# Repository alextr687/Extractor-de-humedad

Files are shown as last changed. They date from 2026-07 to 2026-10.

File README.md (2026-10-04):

# Controlador autónomo para extractor de humedad

Este proyecto nació a partir de un problema muy común en los baños domésticos. Los extractores de humedad suelen conectarse en paralelo con el alumbrado principal, de modo que se activan automáticamente cada vez que alguien enciende la luz. Aunque es una solución sencilla, tiene un inconveniente evidente: el extractor funciona siempre, independientemente de si realmente es necesario.

En mi caso decidí modificar la instalación para que el extractor pudiera accionarse manualmente mediante un interruptor independiente, sustituyendo el interruptor simple existente por uno doble.

La siguiente mejora consistió en instalar un relé temporizado a la desconexión ajustado a 30 minutos. Esto resolvía el problema de olvidarse de apagar el extractor, pero introducía otro distinto: un tiempo fijo rara vez es el adecuado. En ocasiones el baño recuperaba unas condiciones normales en pocos minutos y el extractor continuaba funcionando innecesariamente. En otras, tras una ducha prolongada, treinta minutos resultaban insuficientes para eliminar la humedad.

El objetivo pasó entonces a ser desarrollar un temporizador cuya duración dependiese del estado real del ambiente y no únicamente del tiempo transcurrido.

El proyecto consiste en el diseño de un controlador basado en Arduino capaz de gestionar automáticamente un extractor de humedad utilizando medidas de temperatura y humedad. El sistema mantiene el extractor en funcionamiento el tiempo necesario para reducir la humedad ambiental por debajo de unos umbrales configurables, evitando tanto un funcionamiento insuficiente como un consumo innecesario.

## Diseño

Desde el principio se priorizó la robustez del sistema frente a la complejidad. Los sensores de humedad de bajo coste tienden a producir lecturas erróneas, quedar bloqueados o incluso dejar de responder, especialmente en ambientes cálidos y húmedos como un cuarto de baño. Esto es especialmente relevante en condiciones en las que la humedad tiende a condensar (es decir, que el sensor se encuentre a temperatura de rocío). Por ese motivo el controlador se diseñó siguiendo un principio sencillo: ante cualquier condición anómala, el sistema debe adoptar un comportamiento predecible y seguro.

Para conseguirlo se implementaron distintos mecanismos de protección:

* filtrado de medidas mediante mediana (elimina la mayoría de outliers)
* detección de valores fuera de rango (elimina lecturas erróneas pero validadas por el sensor)
* control de tiempo de respuesta (mide el tiempo de respuesta del sensor para detectar degradación)
* detección de sensor congelado (asegura que el sensor toma medidas reales y no repetidas)
* recuperación automática mediante watchdog (incluye aviso por reinicio automático)
* modo seguro ante fallos persistentes (intento de recuperación; en caso de fallo persistente, apagado automático)
* apagado definitivo cuando no puede garantizarse un funcionamiento fiable (o cuando termina el ciclo de funcionamiento)

El esquema de la máquina de estados está disponible aquí: [Máquina de estados](docs/Programa_Arduino_(UML).pdf). 
El programa completo para Arduino IDE está en: [Programa](firmware/Programa.ino)

Además, el sistema nunca sustituye el control manual del usuario. El extractor continúa estando gobernado en última instancia por el interruptor de la instalación, de modo que siempre puede desconectarse manualmente independientemente del estado del controlador.

## Instalación

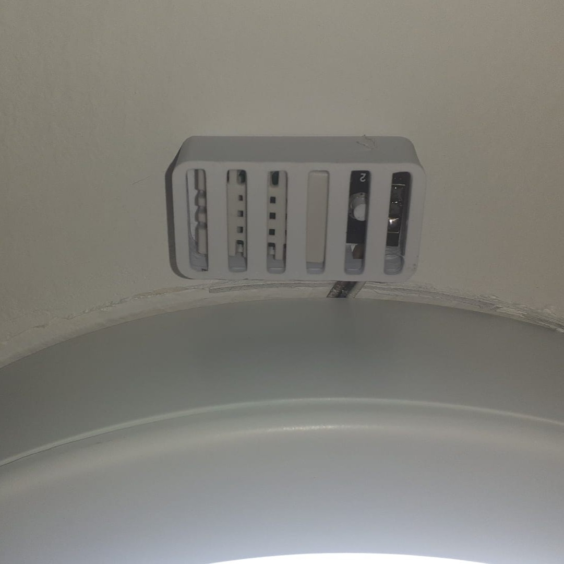
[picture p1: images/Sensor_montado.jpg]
Sensor instalado


El proyecto se integra aprovechando la instalación existente. La fuente de alimentación se encuentra en la caja de derivación del circuito de alumbrado. El controlador (Arduino y relé) está instalado sobre el falso techo, aprovechando el hueco del foco del baño. El sensor DHT22 está situado junto al punto de luz para medir la humedad ambiente. Debe colocarse lo más cerca posible del controlador para evitar ruido eléctrico (el protocolo 1-Wire[^1] es sensible a cables muy largos).  El extractor permanece conectado al interruptor manual existente, utilizándose el controlador únicamente para automatizar su desconexión. Ambos controladores (interruptor y relé) están conectados en serie, de forma que es necesario que ambos coincidan para el encendido, pero cualquiera de los dos puede apagarlo. Hay un esquema eléctrico adjunto. El objetivo fue integrar el sistema sin modificar la apariencia del baño ni añadir elementos visibles, con la única excepción del sensor de humedad relativa y temperatura, que, por su funcionamiento, debe quedar a la vista.
El esquema de la instalación eléctrica está disponible aquí: [Esquema](docs/Esquema_de_instalacion.pdf)

## Resultado

El comportamiento obtenido es considerablemente más natural que el de un temporizador convencional. El extractor permanece funcionando únicamente el tiempo necesario para reducir la humedad y se adapta automáticamente a la duración e intensidad de cada uso del baño. Aunque se trata de un proyecto doméstico, se diseñó aplicando criterios habituales en sistemas embebidos, prestando especial atención a la gestión de errores, la robustez y la seguridad de funcionamiento.

Los resultados están recogidos en la hoja de cálculo adjunta: [Hoja de resultados](tests/Data.xlsx)
En esta se muestran los siguientes datos:

* En el primer libro, dos pruebas en condiciones idénticas. Una de ellas (prueba A) muestra la evolución de la humedad con ventilación natural. La otra (prueba B) muestra la evolución en las mismas condiciones, esta vez con el extractor funcionando. Ambas pruebas terminan cuando los valores de humedad son aceptables (el mismo valor para ambas pruebas). Las condiciones iniciales de ambas pruebas están disponibles en [Condiciones iniciales](docs/Metodologia_para_la_prueba.txt)
* En el segundo libro, una ducha real en condiciones convencionales. Se muestran, además de la evolución de las humedades relativa y absoluta y la evolución de la temperatura, el estado del controlador. Esta gráfica incluye número de errores, de lecturas repetidas y estado de la máquina de estados (esperando o evaluando).
* En el tercer libro se encuentra, de nuevo, una ducha real, esta vez tras unas semanas de uso. En este caso, el controlador se vio obligado a retornar a la etapa de espera tras detectar un aumento de humedad. Se aprecian también en este ejemplo los errores del sensor. Durante esta prueba, 10 de los 130 ciclos de medición presentaron al menos una lectura no válida (7,69 % de los ciclos). Dado que cada ciclo se compone de seis lecturas de sensor independientes, la probabilidad estimada de que una lectura individual falle es de aproximadamente el 1,3 %[^2].

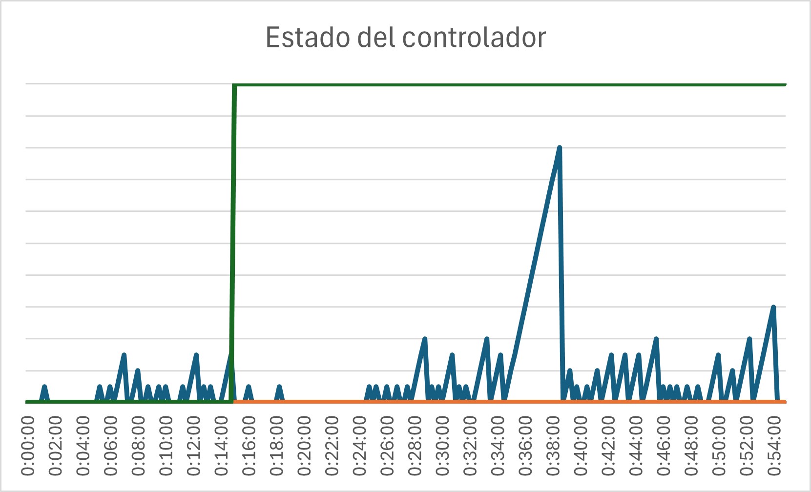
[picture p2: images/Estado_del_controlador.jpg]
Gráfica 1

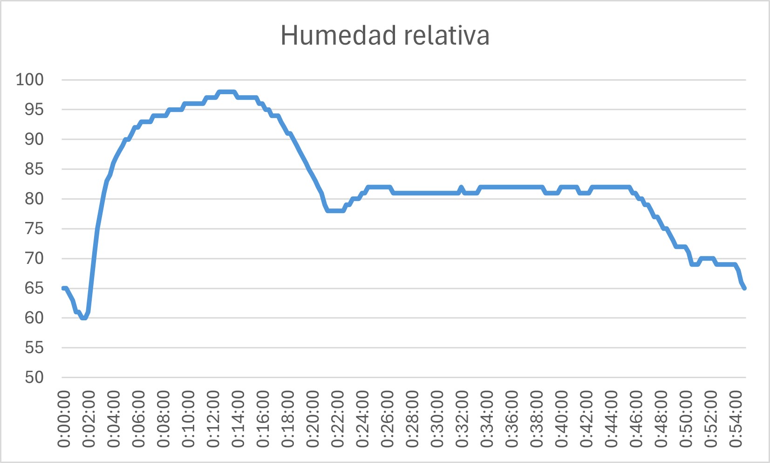
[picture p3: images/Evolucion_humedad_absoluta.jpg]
Gráfica 2

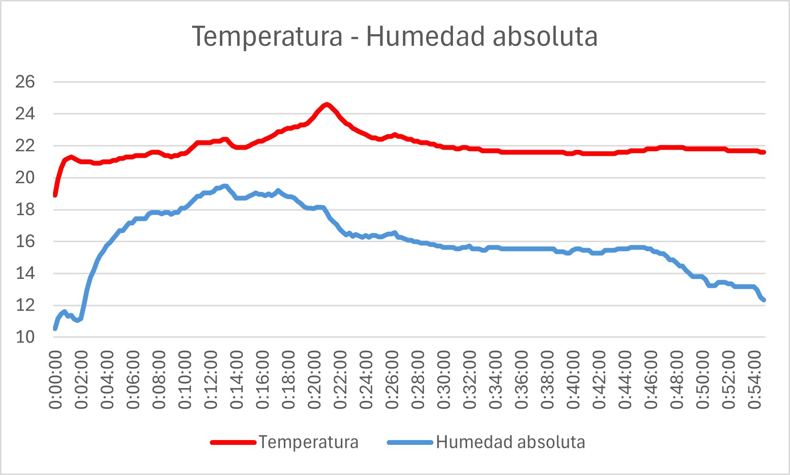
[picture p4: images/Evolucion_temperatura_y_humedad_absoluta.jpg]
Gráfica 3


Para transformar los datos del controlador en información interpretable por Excel, el siguiente parser es un script de Python que transforma documentos de texto con el formato de la salida del monitor serie en documentos tipo csv. [Script](scripts/Serial_to_csv.py)

El código [Programa_logger](firmware/Programa_logger.ino) tiene exactamente la misma función, pero añade el registro de datos en una SD. El programa registra cada 15 segundos los 9 parámetros que considera para la toma de decisiones (aproximadamente lo mismo que se imprime por monitor serie. Este registro puede ser interesante para estudios de fiabilidad a largo plazo. El resultado de la instalación del lector SD queda así:

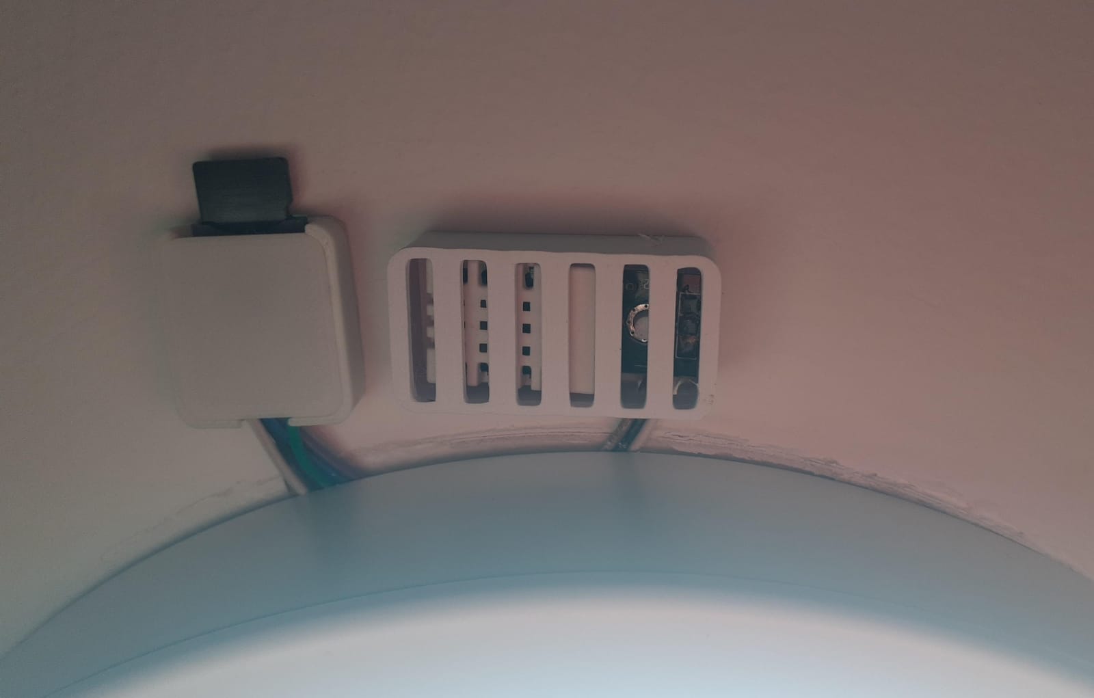
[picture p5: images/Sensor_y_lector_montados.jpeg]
Sensor y lector montados


Los archivos del registro están subidos, semana a semana, en la carpeta [long_term_data](long_term_data). Solamente identifican la semana del año, pero no el día ni la hora individualmente. 

## BOM

* Arduino Nano
* DHT22 (sustituible por DHT11 o DHT21/AM2301)
* Módulo de relé
* Zumbador pasivo
* Fuente de alimentación (5V, 5W)
* Lector de tarjetas micro-SD

## Limitaciones y posibles mejoras

* Utiliza un DHT22, que no es un sensor industrial.
* El Arduino Nano no es la plataforma definitiva para un producto comercial.
* Los umbrales son configurables únicamente modificando el firmware.

En cuanto al funcionamiento del esquema tal cual está diseñado, hay un efecto que puede resultar indeseable al usuario. La mayoría de las fuentes de alimentación tienen filtros en su salida compuestos por uno o varios condensadores, que alargan el tiempo que la fuente puede suministrar energía incluso cuando ya está desconectada. Esto se traduce en que el Nano puede seguir estando alimentado, y evitando activamente el encendido del extractor de humedad, cuando el usuario apaga y enciende el interruptor para reiniciar el sistema. Ocurrirá solamente si el usuario enciende el interruptor sin haber dejado tiempo suficiente para que se descarguen los condensadores de la fuente. Este problema puede solucionarse simplemente aumentando la carga de la fuente, con una o varias resistencias en paralelo (lo que se conoce como *bleeder resistor*), o moviendo el interruptor a la salida de la fuente, para que interrumpa solamente la alimentación del Nano (esta última solución contraviene las buenas prácticas de eficiencia energética, pero es igualmente efectiva).

## Ideas

* PCB diseñada específicamente para el proyecto.
* Sensor SHT31 o BME280.
* Configuración mediante Bluetooth o Wi-Fi.
* Actualización OTA (en caso de migrar a ESP32).
* Algoritmo adaptativo según estación del año.
* Segundo sensor fuera del baño, para comparar la humedad objetivo con la conseguida (en lugar de esperar indefinidamente hasta un umbral que puede ser inalcanzable). Mejor opción que el algoritmo adaptativo según la estación, pero más difícil de implementar.

[^1]: El DHT22 no utiliza el protocolo estándar 1-Wire® de Maxim/Dallas (que requiere direccionamiento de 64 bits y drenador abierto con resistencia pull-up), sino un protocolo propietario monobus de 40 bits impulsado por temporización de pulsos.

[^2]: Matemáticamente 1-(1-p)^6 = 0,0769 → p ≈ 1,33%. Sin embargo, el análisis omite que en sensores DHT22 en ambientes saturados (100% HR / temperatura de rocío) los fallos de lectura presentan dependencia temporal/correlación por saturación de la membrana, por lo que la asunción de independencia estocástica estricta no es válida sin un filtrado previo. En cualquier caso, sirve como aproximación «a ojo de buen cubero».

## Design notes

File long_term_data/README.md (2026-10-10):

En esta carpeta se almacenan los datos recogidos por el controlador de forma autónoma. 

Cambios en el programa por orden cronológico de implementación:

* 11/10/2026: commit *Fe de errores. Corrección de la llamada a registrar_datos* (55f73cce03b235f29c37be379a4c0f51117d4510)

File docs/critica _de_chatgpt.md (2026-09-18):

Alejandro: 

Quiero que realices una **evaluación técnica completa, crítica y objetiva de este proyecto**. No quiero una valoración superficial ni que simplemente destaques lo positivo. Quiero que intentes detectar problemas, puntos débiles, errores de diseño, decisiones mejorables y oportunidades de mejora, pero sin proponer cambios por el mero hecho de cambiar algo.

### 1\. Comprensión del proyecto

Antes de evaluarlo, reconstruye mentalmente el proyecto a partir de toda la información que te proporcione.

Identifica:

-   Objetivo principal.
-   Objetivos secundarios.
-   Requisitos y restricciones.
-   Arquitectura general.
-   Principio de funcionamiento.
-   Componentes y materiales.
-   Diseño mecánico.
-   Diseño eléctrico/electrónico.
-   Software, si lo hay.
-   Proceso de fabricación y montaje.
-   Uso previsto y condiciones de funcionamiento.

Si existe información insuficiente para entender correctamente alguna parte importante, indícalo explícitamente en lugar de asumirla.

### 2\. Evaluación técnica

Analiza por separado:

**Diseño funcional**

-   Si cumple realmente el objetivo planteado.
-   Robustez del funcionamiento.
-   Posibles modos de fallo.
-   Comportamiento en condiciones normales y anómalas.
-   Dependencias o puntos únicos de fallo.

**Diseño eléctrico/electrónico**

-   Dimensionamiento.
-   Tensiones, corrientes y potencias.
-   Protecciones.
-   Calentamiento y disipación.
-   Caídas de tensión.
-   Compatibilidad entre componentes.
-   Seguridad eléctrica.
-   Fiabilidad de conexiones y cableado.

**Diseño mecánico**

-   Resistencia.
-   Rigidez.
-   Uniones.
-   Tolerancias.
-   Concentraciones de tensión.
-   Vibraciones, golpes o cargas relevantes.
-   Protección frente al entorno.
-   Facilidad de montaje y desmontaje.

**Materiales y fabricación**

-   Adecuación de los materiales.
-   Proceso de fabricación.
-   Tolerancias razonables.
-   Limitaciones del proceso utilizado.
-   Repetibilidad.
-   Facilidad de fabricación.
-   Posibles problemas de envejecimiento o degradación.

**Software**, si procede:

-   Arquitectura.
-   Lógica de funcionamiento.
-   Estados y transiciones.
-   Gestión de errores.
-   Temporización.
-   Uso de memoria y recursos.
-   Bloqueos o comportamientos inesperados.
-   Mantenibilidad.

### 3\. Seguridad y fiabilidad

Busca específicamente situaciones en las que el proyecto pueda:

-   Fallar.
-   Dañarse.
-   Provocar daños a otros elementos.
-   Crear un riesgo para las personas.
-   Degradarse con el tiempo.
-   Comportarse de forma distinta a la esperada.

Distingue entre:

-   Problemas demostrados.
-   Riesgos técnicamente plausibles.
-   Posibilidades meramente especulativas.

No presentes una posibilidad hipotética como si fuera un problema real.

### 4\. Cumplimiento técnico y normativo

Cuando sea relevante, analiza las normas, reglamentos o buenas prácticas aplicables.

Si haces referencia a una norma, reglamento o requisito legal:

-   Indica cuál es.
-   Explica qué parte es relevante.
-   No inventes requisitos.
-   Distingue entre obligación normativa y recomendación de diseño.

Si no puedes verificar una cuestión normativa, dilo explícitamente.

### 5\. Análisis de las decisiones de diseño

Para cada decisión importante, intenta determinar:

1.  Qué problema resuelve.
2.  Qué ventajas proporciona.
3.  Qué inconvenientes introduce.
4.  Qué alternativas razonables existen.
5.  En qué condiciones sería preferible cada alternativa.

No presupongas que una alternativa es mejor simplemente porque sea más sofisticada, cara, moderna o técnicamente compleja.

### 6\. Mejoras

Propón mejoras únicamente cuando exista una razón técnica concreta.

Para cada mejora indica:

-   Problema que resuelve.
-   Cambio propuesto.
-   Beneficio esperado.
-   Coste o complejidad adicional.
-   Posibles inconvenientes.
-   Prioridad.

Clasifica las mejoras como:

-   **Crítica:** debería corregirse antes de utilizar el proyecto.
-   **Importante:** mejora significativamente la seguridad, fiabilidad o funcionamiento.
-   **Conveniente:** aporta una mejora razonable, pero no es necesaria.
-   **Opcional:** mejora principalmente aspectos secundarios, estética, comodidad o experimentación.

No propongas cambios si el diseño actual ya es adecuado para su objetivo.

### 7\. Evaluación experimental

Si proporciono mediciones, pruebas o resultados experimentales:

-   Comprueba si las conclusiones están justificadas por los datos.
-   Busca variables no controladas.
-   Analiza errores de medida.
-   Diferencia correlación de causalidad.
-   Comprueba si el número de pruebas es suficiente para la conclusión que se pretende obtener.
-   Propón experimentos adicionales solamente cuando puedan aportar información relevante.

Si hay cálculos, compruébalos.

Si hay datos suficientes, realiza tú mismo los cálculos necesarios para comprobarlos.

### 8\. Iteraciones del diseño

Si proporciono versiones anteriores del proyecto, compara las iteraciones.

Determina:

-   Qué problemas solucionó cada versión.
-   Qué características se conservaron correctamente.
-   Qué compromisos aparecieron.
-   Si alguna modificación empeoró otro aspecto.
-   Si existe alguna mejora que todavía tenga una justificación técnica clara.

No supongas que una versión posterior es necesariamente mejor.

### 9\. Calidad de ingeniería

Evalúa también el proyecto como trabajo de ingeniería:

-   Claridad de requisitos.
-   Trazabilidad entre requisitos y soluciones.
-   Justificación de decisiones.
-   Coherencia entre diseño teórico y construcción real.
-   Documentación.
-   Reproducibilidad.
-   Mantenibilidad.
-   Facilidad de reparación.
-   Escalabilidad o reutilización, cuando sea relevante.
-   Relación entre complejidad y beneficio.

### 10\. Valoración final

Termina con una síntesis estructurada que incluya:

**Fortalezas principales**  
Qué está particularmente bien resuelto y por qué.

**Debilidades principales**  
Qué aspectos presentan problemas o riesgos y por qué.

**Errores o decisiones cuestionables**  
Solo cuando exista una justificación técnica clara.

**Mejoras recomendadas**  
Ordenadas por prioridad, sin convertir la lista en una colección de cambios cosméticos.

**Aspectos que NO modificarías**  
Indica qué decisiones consideras adecuadas y explica por qué. No busques mejoras artificiales.

**Preguntas pendientes**  
Solo las preguntas cuya respuesta pueda cambiar significativamente la evaluación.

### Criterios importantes

Quiero una evaluación **crítica, no complaciente**, pero también **proporcional al objetivo real del proyecto**.

No evalúes un proyecto doméstico como si fuera un producto industrial certificado si ese no es su propósito. Evalúa cada decisión en función de sus requisitos, entorno de uso, coste, complejidad y nivel de exigencia.

No confundas:

-   «Podría hacerse de otra manera» con «está mal diseñado».
-   «Existe una solución más sofisticada» con «la solución actual es inadecuada».
-   «No está certificado» con «es técnicamente inseguro».
-   Preferencias personales con requisitos técnicos.

Cuando critiques una decisión, explica **el mecanismo físico, matemático, eléctrico, mecánico o lógico que justifica la crítica**.

Cuando una conclusión dependa de una suposición, comienza esa línea con **\[Inferencia\]** o **\[No verificado\]**.

Si existen varias soluciones técnicamente válidas, no elijas arbitrariamente una: explica el compromiso entre ellas.

No intentes agradarme ni defender mis decisiones. Tampoco las critiques por defecto. Tu objetivo es determinar, con la información disponible, **qué está bien, qué está mal, qué es mejorable y qué no merece la pena tocar**.

Quiero que señales tanto los problemas que yo pueda no haber detectado como las decisiones que están bien justificadas aunque inicialmente puedan parecer poco convencionales.

Finalmente, si detectas que falta información importante, **pregúntamela antes de emitir una conclusión definitiva sobre ese aspecto**.

A continuación te adjunto toda la documentación del proyecto. Todo el contexto necesario está en el documento llamado README  
Extractor-de-humedad-(GitHub).zip

ChatGPT: 

Ha pensado durante 3m 28s

He revisado el contenido del ZIP completo: README, firmware, máquina de estados, esquema eléctrico, metodología de ensayo, datos brutos, Excel, script de conversión, imágenes y modelo STL. La evaluación siguiente se basa en esa documentación y, donde corresponde, en documentación técnica y normativa externa actualizada.

## 1\. Reconstrucción del proyecto

### Objetivo principal

El proyecto no es realmente un "extractor automático" completo en el sentido de detectar una ducha y arrancar el ventilador por sí mismo.

Es más preciso describirlo como:

> **Controlador automático de desconexión de un extractor previamente activado manualmente, cuya duración se adapta a la evolución de temperatura y humedad.**

El interruptor del baño sigue siendo el mando primario. Al activar el sistema:

1.  Arduino arranca.
    
2.  El relé se pone en ON.
    
3.  El extractor queda habilitado, siempre que el interruptor manual también esté cerrado.
    
4.  Durante 15 minutos no se permite terminar el ciclo por humedad.
    
5.  Después se evalúa periódicamente la humedad.
    
6.  El extractor se desconecta cuando:
    
    -   humedad absoluta ≤ 13 g/m³ **y**
        
    -   humedad relativa ≤ 65 %,
        
    -   o se alcanza el tiempo máximo de 60 min,
        
    -   o se detectan determinados fallos persistentes del sensor.
        
7.  Arduino apaga el relé y entra en `SLEEP_MODE_PWR_DOWN` indefinidamente.

Esta arquitectura es coherente con el problema que planteas: **automatizar el apagado sin perder el control manual**.

---

# 2\. Arquitectura y funcionamiento

La arquitectura general es sencilla:

**Red 230 V → interruptor manual → contacto del relé → extractor**

y, en paralelo desde la alimentación:

**Red → fuente 5 V → Arduino → relé + DHT22 + zumbador**

El DHT22 proporciona temperatura y humedad. El software calcula además humedad absoluta mediante:

AH\=273.15+T2.1674RHPv(T)

con una aproximación de Magnus-Tetens para la presión de vapor.

La máquina de estados es:

-   `etapaEspera`
    
-   `etapaTest`
    
-   `etapaError`
    
-   `etapaHumedad`
    
-   `etapaTiempo`
    
-   `etapaApagado`

La idea general está bien estructurada para un proyecto embebido pequeño. No hay una arquitectura innecesariamente compleja.

---

# 3\. Lo que está particularmente bien resuelto

## 3.1. La decisión de utilizar humedad absoluta además de relativa

Esta es, en mi opinión, una de las decisiones técnicamente más justificadas del proyecto.

La humedad relativa depende mucho de la temperatura. Por ejemplo, la misma cantidad de vapor puede representar porcentajes de HR muy distintos a diferentes temperaturas.

Usar simultáneamente:

-   HR ≤ 65 %
    
-   AH ≤ 13 g/m³

evita depender exclusivamente de una variable que cambia con la temperatura.

El cálculo implementado es matemáticamente coherente para las unidades utilizadas.

**No modificaría esto simplemente por utilizar otro algoritmo más sofisticado.**

---

## 3.2. El límite de tiempo máximo

El hecho de disponer de un límite duro de funcionamiento es bueno.

Un controlador basado exclusivamente en:

> "seguir ventilando hasta que el sensor diga que todo está bien"

tiene un problema evidente si el sensor o el modelo ambiental fallan.

El límite de 60 minutos introduce una barrera independiente.

El problema está en cómo se implementa ese límite, que veremos más adelante.

---

## 3.3. La mediana de tres medidas

La función:

```
C++

```
floatmediana(floata, floatb, floatc)
```
```

está correctamente implementada.

Además, utilizar una mediana es razonable para un sensor barato en un entorno donde pueden aparecer lecturas puntuales incorrectas.

No veo justificación para sustituirla por un filtro mucho más complejo.

---

## 3.4. El sistema no confía ciegamente en `NaN`

El software contempla:

-   `NaN`
    
-   valores fuera de rango
    
-   lecturas excesivamente lentas
    
-   valores repetidos
    
-   watchdog
    
-   recuperación
    
-   segundo fallo

Eso demuestra una preocupación real por la degradación del sensor, y no solamente por el funcionamiento nominal.

La separación entre:

> "el sensor ha fallado una vez"

y

> "el sistema ya no confía en él"

es conceptualmente buena.

---

## 3.5. El watchdog

Utilizar watchdog es apropiado.

Especialmente porque el propio código reconoce que el timeout software:

```
C++

```
if (millis() -tiempoLectura>TIMEOUT_SENSOR)
```
```

**no puede detectar un bloqueo dentro de `dht.readHumidity()`** si esa función no retorna.

El watchdog cubre precisamente esa clase de problema.

La filosofía es correcta aunque la estrategia completa tiene una deficiencia importante que veremos después.

---

## 3.6. El apagado final es deliberadamente definitivo

Esta parte:

```
C++

```
digitalWrite(RELAY, LOW);
...
wdt_disable();
...
set_sleep_mode(SLEEP_MODE_PWR_DOWN);
...
while (true) sleep_cpu();
```
```

hace que el sistema no intente reiniciar continuamente el ciclo.

Para este proyecto es una decisión razonable.

La siguiente activación del interruptor vuelve a alimentar el sistema y comienza un nuevo ciclo.

No intentaría convertir esto en un sistema "siempre encendido" simplemente porque técnicamente sea posible.

---

# 4\. Problemas y puntos débiles importantes

Aquí empieza la parte crítica.

Hay varios problemas que considero reales, no simplemente preferencias.

---

# 4.1. \[Crítico\] El watchdog puede provocar reinicios indefinidos sin llegar al apagado seguro

Este es probablemente el problema de software más importante.

El flujo es:

```
C++

```
wdt_enable(WDTO_8S);
```
```

Si el programa se bloquea, el watchdog reinicia el microcontrolador.

Pero después del reinicio:

```
C++

```
digitalWrite(RELAY, HIGH);
```
```

vuelve a activar el extractor.

Y el programa continúa funcionando.

Si el sensor o alguna condición externa provoca sistemáticamente:

> arranque → bloqueo → watchdog → reinicio → arranque → bloqueo...

el sistema puede permanecer indefinidamente en ese ciclo.

No existe un contador persistente del tipo:

> "tres watchdog resets consecutivos → fallo permanente → relé OFF".

El propio README presenta el watchdog como mecanismo de recuperación y el fallo persistente como condición de apagado, pero **un reinicio por watchdog no incrementa `contadorFallos`**.

### Consecuencia

\[Inferencia\] Un fallo que produzca un bloqueo repetitivo del firmware puede mantener el extractor funcionando indefinidamente.

No significa que vaya a ocurrir en condiciones normales, pero el mecanismo de protección no cubre realmente ese caso.

### Mejora

**Importante**

Registrar resets por watchdog en una variable persistente durante el ciclo de alimentación y establecer, por ejemplo:

> primer watchdog → recuperación  
> segundo watchdog → recuperación controlada  
> watchdog repetido → relé OFF

La implementación exacta dependería de cómo quieras tratar la pérdida de sensor.

---

# 4.2. \[Crítico\] El "tiempo máximo de 60 minutos" no es realmente un máximo global

Esta línea es especialmente importante:

```
C++

```
tiempoInicio = millis();
```
```

se ejecuta al principio.

Pero también se ejecuta cuando se detecta:

```
C++

```
Nuevoaumento dehumedad detectado. Reiniciando temporizador...
```
```

Por tanto, el límite:

```
C++

```
TIEMPO_MAX = 3600000
```
```

es realmente:

> **60 minutos desde el último reinicio del temporizador**

y no:

> **60 minutos desde el comienzo del ciclo completo.**

Por ejemplo, conceptualmente podría suceder:

-   minuto 0 → comienza ciclo
    
-   minuto 50 → humedad vuelve a aumentar
    
-   se reinicia `tiempoInicio`
    
-   minuto 65 → todavía pueden quedar 45 minutos
    
-   minuto 110 → vuelve a aumentar
    
-   se reinicia otra vez

\[Inferencia\] Bajo una secuencia suficientemente persistente de aumentos de humedad, el extractor podría funcionar durante un tiempo arbitrariamente superior a 60 minutos.

Eso contradice parcialmente la descripción de "tiempo máximo de funcionamiento".

### Mejora

**Importante**

Separar:

```
```
tiempoInicioCiclo
tiempoInicioEvaluacion
```
```

y decidir explícitamente cuál de ellos limita el tiempo absoluto.

Yo conservaría el mecanismo de reinicio del temporizador si tiene una justificación experimental, pero **mantendría además un timeout absoluto independiente**.

---

# 4.3. La afirmación de "seis lecturas independientes" no es correcta

El README afirma:

> cada ciclo se compone de seis lecturas de sensor independientes.

El código hace:

```
C++

```
h[0] = dht.readHumidity();
t[0] = dht.readTemperature();

h[1] = dht.readHumidity();
t[1] = dht.readTemperature();

h[2] = dht.readHumidity();
t[2] = dht.readTemperature();
```
```

Pero la librería Adafruit DHT utiliza un intervalo mínimo de 2 s y, si no ha pasado ese tiempo, devuelve la medición anterior en vez de iniciar una nueva adquisición. La implementación actual de la librería muestra explícitamente `MIN_INTERVAL 2000` y ese comportamiento. [GitHub+1](https://github.com/adafruit/DHT-sensor-library/blob/master/DHT.cpp?utm_source=chatgpt.com)

En este proyecto hay 5 s entre ciclos, por lo que las tres adquisiciones separadas por 5 s sí son adquisiciones nuevas.

Pero dentro de cada adquisición:

```
```
readHumidity()
readTemperature()
```
```

ambas proceden de **la misma trama de 40 bits del DHT22**.

Por tanto:

-   3 adquisiciones físicas del DHT22
    
-   cada adquisición proporciona HR + T

No son seis mediciones independientes.

Además, el DHT22 tiene una frecuencia máxima de aproximadamente 0,5 Hz, es decir, una medición cada 2 s. [Adafruit+1](https://www.adafruit.com/product/385?utm_source=chatgpt.com)

---

## 4.4. La estimación estadística de la tasa de error está mal planteada

El README calcula:

1−(1−p)6\=0.0769

y obtiene:

p≈1.33%

Pero, por lo anterior, el supuesto de seis lecturas independientes no corresponde al código.

Si se consideran **tres adquisiciones independientes** por ciclo:

1−(1−p)3\=0.0769

se obtiene aproximadamente:

p≈2.63%

Y utilizando los datos brutos disponibles, hay además una discrepancia en el número de ciclos.

El fichero `Ducha_real_II.txt` contiene:

-   129 líneas de medición, contando errores como ciclos de medición.
    
-   10 de ellas son errores.
    
-   1 evento explícito de reinicio del temporizador.

Eso da:

12910\=7.75%

no 7,69 %.

La diferencia porcentual es pequeña, pero para un proyecto que intenta caracterizar estadísticamente la fiabilidad del sensor, **la metodología debería ser más rigurosa**.

---

# 4.5. El contador de "sensor congelado" puede confundir estabilidad real con fallo

El criterio es:

```
C++

```
if (
  fabs(humedad-prev_humedad) <RESOLUCION_SENSOR&&fabs(temperatura-prev_temperatura) <RESOLUCION_SENSOR
)
    contadorIguales++;
```
```

y:

```
C++

```
MAX_LECTURAS_IGUALES = 20;
```
```

es decir, unos 5 minutos.

El problema es que:

> "el sensor lleva cinco minutos dando exactamente lo mismo"

no implica necesariamente:

> "el sensor está congelado".

El propio DHT22 tiene resolución de 0,1 %HR y 0,1 °C, y es un sensor relativamente lento. [GitHub+1](https://github.com/adafruit/DHT-sensor-library/blob/master/DHT.cpp?utm_source=chatgpt.com)

Además, en los datos reales aparece un ejemplo muy interesante:

```
```
21.6 °C
82.0 %
15.55 g/m³
```
```

mantenido durante aproximadamente cuatro minutos.

El contador llegó a:

```
```
16
```
```

sin que existiese evidencia de fallo.

Por tanto, el sistema estuvo bastante cerca del umbral de "sensor congelado" en una situación que parece perfectamente plausible.

### Evaluación

**Riesgo técnicamente plausible, no fallo demostrado.**

El criterio debería considerar algo más que igualdad exacta, por ejemplo:

-   tiempo sin variación;
    
-   coherencia entre temperatura y humedad;
    
-   respuesta ante una pequeña perturbación;
    
-   quizá evolución de la señal en ventanas más largas.

Pero no sustituiría automáticamente el método por otro más complejo.

---

# 4.6. `contadorHumedadAlta` tampoco cuenta realmente "2 minutos consecutivos"

El comentario dice:

```
C++

```
CICLOS_HUMEDAD_ALTA = 8//2 minuto con humedad relativa aumentando
```
```

pero el código:

```
C++

```
if ((humedad-prev_humedad) >=UMBRAL_AUMENTO)
    contadorHumedadAlta++;
```
```

**no reinicia el contador cuando la humedad deja de aumentar**.

Solamente lo reduce ante un error:

```
C++

```
if (variableError<0)
    contadorHumedadAlta--;
```
```

Por tanto, el contador representa:

> número acumulado de incrementos suficientemente grandes

y no:

> ocho incrementos consecutivos durante dos minutos.

Eso es una discrepancia entre especificación y código.

\[Inferencia\] Una humedad que oscile alrededor de un nivel alto podría acumular suficientes incrementos separados para reiniciar el temporizador aunque no exista una tendencia ascendente continua.

Esto sí merece corrección porque afecta directamente a la lógica funcional.

---

# 4.7. El watchdog está bien planteado, pero el relé tiene una filosofía "fail ON"

En `setup()`:

```
C++

```
digitalWrite(RELAY, HIGH);
```
```

y el relé permanece activado durante todo el funcionamiento normal.

Eso significa que ante determinados fallos:

-   bloqueo de software;
    
-   reinicio;
    
-   comportamiento inesperado del programa;

el estado deseado del sistema es **extractor encendido**.

Esto tiene una justificación razonable:

> ante incertidumbre sobre la humedad, es preferible ventilar.

Pero no debe confundirse con un estado "seguro" en todos los sentidos.

Para este proyecto:

-   fallo ON → más consumo / más funcionamiento;
    
-   fallo OFF → humedad potencialmente no evacuada.

El primero parece razonable para un extractor doméstico.

Además, el interruptor manual proporciona una segunda vía de desconexión, lo cual es una buena decisión arquitectónica.

---

# 5\. DHT22: elección y tratamiento

El DHT22 es suficiente para un proyecto doméstico de estas características.

El fabricante/distribuidor documenta aproximadamente:

-   0–100 % HR;
    
-   ±2–5 % HR;
    
-   −40 a 80 °C;
    
-   ±0,5 °C;
    
-   máximo 0,5 Hz. [Adafruit](https://www.adafruit.com/product/385?utm_source=chatgpt.com)

Por tanto, **no considero que utilizar DHT22 sea un error de diseño**.

El hecho de que no sea industrial tampoco es, por sí mismo, una deficiencia.

### Donde sí veo limitación

El proyecto intenta hacer decisiones relativamente importantes a partir de diferencias pequeñas:

```
C++

```
AH_LIMITE = 13.0
H_LIMITE = 65.0
```
```

y el propio sensor tiene una precisión de humedad bastante peor que 1 % en términos absolutos. [Adafruit](https://www.adafruit.com/product/385?utm_source=chatgpt.com)

Esto no significa que el sistema no funcione. Significa que:

> 65 % no debe interpretarse como una frontera físicamente exacta.

En realidad el controlador utiliza los umbrales como **criterios de decisión**, no como medición metrológica.

Eso está bien si se entiende así.

---

# 6\. Diseño eléctrico

Aquí la documentación es mucho más débil que el software.

## 6.1. Potencia de 5 V

Una fuente de:

**5 V × 5 W = 1 A**

tiene, en principio, margen enorme para:

-   Nano;
    
-   DHT22;
    
-   relé;
    
-   zumbador.

El DHT22 consume del orden de 2,5 mA durante conversión. [Adafruit](https://www.adafruit.com/product/385?utm_source=chatgpt.com)

Por tanto, **5 W no parece una elección problemática por falta de potencia**.

Pero falta el dato realmente importante:

> modelo exacto de la fuente.

No sabemos:

-   aislamiento;
    
-   certificaciones;
    
-   protección contra cortocircuito;
    
-   temperatura máxima;
    
-   comportamiento térmico;
    
-   grado IP;
    
-   corriente real disponible;
    
-   tipo de montaje;
    
-   si es una fuente apropiada para instalación permanente.

---

## 6.2. Atención al punto de alimentación del Nano

El esquema parece alimentar el Nano directamente con 5 V regulados.

Eso es correcto para el pin de 5 V.

No sería equivalente introducir 5 V por VIN.

La documentación actual de Arduino especifica para el Nano clásico alimentación mediante USB o VIN, siendo VIN una entrada que pasa por el regulador; la documentación del modelo muestra 7–12 V como rango de VIN. [Documentación de Arduino+1](https://docs.arduino.cc/resources/datasheets/A000005-datasheet.pdf?utm_source=chatgpt.com)

Por tanto:

**5 V regulados → pin 5V**

es la arquitectura que corresponde al esquema.

Esto debería quedar escrito explícitamente en la documentación.

---

# 7\. Inconsistencia importante: Nano frente a UNO

El BOM dice:

> Arduino Nano

pero el esquema eléctrico contiene gráficamente un:

> **Arduino UNO**

No es simplemente estética.

Los pines utilizados son compatibles conceptualmente porque ambos emplean ATmega328P en las versiones clásicas, pero:

-   dimensiones;
    
-   conectores;
    
-   montaje;
    
-   alimentación;
    
-   ubicación física de pines;

son diferentes.

Por tanto, para reproducibilidad esto es un error documental claro.

### Prioridad

**Conveniente / Importante para documentación**, pero no necesariamente un problema funcional.

Yo corregiría el esquema para representar exactamente el hardware instalado.

---

# 8\. Relé y extractor

Aquí falta información para cerrar la evaluación.

No aparece:

-   fabricante/modelo del módulo de relé;
    
-   tensión de bobina;
    
-   corriente de bobina;
    
-   especificación del contacto;
    
-   categoría de utilización;
    
-   carga inductiva admisible;
    
-   tensión nominal exacta del extractor;
    
-   potencia del extractor;
    
-   corriente de arranque.

Esto es importante.

Un extractor es un motor, por lo que la carga no debe tratarse simplemente como:

> "por ejemplo 30 W → 0,13 A"

porque el comportamiento durante conmutación es diferente de una resistencia.

Los fabricantes de automatización recomiendan protección frente a transitorios de cargas inductivas AC mediante elementos apropiados como RC snubber o varistor, y advierten de que una carga inductiva puede acabar soldando los contactos de un relé. [iPortal 2+1](https://iportal2.schneider-electric.com/Contents/docs/Modicon%20M171%20Electronic%20Expansion%20Valve%20drivers_User%20Guide.pdf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)

En el esquema no aparece ningún:

-   RC snubber;
    
-   MOV/varistor;
    
-   otro supresor.

### Evaluación

**Riesgo técnicamente plausible.**

No puedo afirmar que el relé vaya a fallar sin conocer el extractor y el relé.

Pero sí considero que la ausencia de esta información es una laguna de diseño eléctrico.

### Mejora

**Importante**

Documentar:

1.  modelo exacto del extractor;
    
2.  corriente nominal;
    
3.  tipo de motor;
    
4.  modelo exacto del relé;
    
5.  capacidad de conmutación para carga inductiva;
    
6.  protección contra transitorios.

No añadiría un snubber arbitrariamente sin esos datos.

---

# 9\. Protección eléctrica y normativa

Si la instalación está en España, el marco principal es el **REBT, Real Decreto 842/2002**, cuya versión consolidada disponible en BOE tiene actualización publicada el 3 de septiembre de 2025. [BOE](https://www.boe.es/buscar/act.php?id=BOE-A-2002-18099)

Para un baño son particularmente relevantes:

-   ITC-BT-24 — protección contra contactos eléctricos;
    
-   ITC-BT-27 — locales con bañera o ducha;
    
-   ITC-BT-19/20/21 — instalación interior y canalizaciones;
    
-   ITC-BT-22 — sobreintensidades;
    
-   ITC-BT-51 — automatización.

La ITC-BT-27 define los volúmenes del baño y especifica que **los falsos techos no se consideran barreras para separar volúmenes**. [BOE](https://www.boe.es/buscar/act.php?id=BOE-A-2002-18099)

Esto es relevante porque la frase:

> "el controlador está instalado sobre el falso techo"

no basta para determinar si está fuera de los volúmenes reglamentarios.

La ITC-BT-27 establece también requisitos de protección y de selección de material según el volumen, incluidos grados de protección IP y condiciones específicas para determinados equipos. [BOE](https://www.boe.es/buscar/act.php?id=BOE-A-2002-18099)

Además, la ITC-BT-51 exige que los nodos, actuadores y entradas de sistemas de automatización cumplan las condiciones de seguridad y compatibilidad electromagnética aplicables y que se respeten las instrucciones de instalación de los fabricantes. [BOE](https://www.boe.es/buscar/act.php?id=BOE-A-2002-18099)

### Lo que no puedo concluir todavía

\[No verificado\] No puedo afirmar que la instalación concreta cumpla el REBT porque el repositorio no documenta suficientemente:

-   posición exacta respecto a ducha;
    
-   altura del falso techo;
    
-   volúmenes reglamentarios;
    
-   envolvente;
    
-   IP;
    
-   fuente de alimentación concreta;
    
-   protecciones aguas arriba;
    
-   diferencial;
    
-   sección y tipo de conductores;
    
-   sistema de canalización;
    
-   conexiones;
    
-   aislamiento entre red y SELV/MBTS.

Esto es una **pregunta pendiente importante**, no un incumplimiento demostrado.

---

# 10\. Un aspecto positivo del esquema eléctrico

Hay una decisión que sí me parece especialmente buena:

## Interruptor manual + relé en serie

El sistema no depende completamente del Arduino para poder desconectar el extractor.

Si:

-   Arduino falla;
    
-   relé queda activado;
    
-   firmware se bloquea;

el usuario conserva el interruptor manual.

Eso introduce una barrera independiente.

No lo cambiaría por un sistema donde Arduino tenga autoridad absoluta sobre el motor.

---

# 11\. Alimentación y "bleeder resistor"

El README identifica correctamente el problema de los condensadores de la fuente:

> apagar y volver a encender rápidamente puede no provocar realmente un reinicio del Arduino.

Esto es técnicamente correcto.

Pero hay una consideración:

### El bleeder

Puede resolver el problema, pero consume energía permanentemente.

### Interruptor después de la fuente

Puede producir un apagado más completo del controlador, pero modifica la arquitectura energética.

El README reconoce ambos compromisos.

**No considero necesario modificarlo si el comportamiento actual no resulta molesto.**

Es un buen ejemplo de una decisión donde no hay una solución universalmente superior.

---

# 12\. Diseño mecánico

El STL `Caja_sensor_humedad.stl` es una pieza cerrada y geométricamente coherente.

He comprobado el modelo y sus dimensiones globales son aproximadamente:

**37 × 40 × 13 mm**

y la malla es *watertight*.

La ventilación de la carcasa es además coherente con el hecho de que el DHT22 necesita contacto con el aire.

## Lo que falta documentar

No consta:

-   material de impresión;
    
-   espesor de pared;
    
-   orientación;
    
-   tolerancias;
    
-   fijación;
    
-   sistema de alivio de tensión del cable;
    
-   resistencia a condensación;
    
-   comportamiento tras envejecimiento.

La carcasa no necesita ser hermética; de hecho, eso sería contraproducente para un sensor ambiental.

Pero sí necesita proteger razonablemente frente a:

-   condensación;
    
-   gotas;
    
-   polvo;
    
-   manipulación accidental.

---

# 13\. Posible problema térmico del sensor

El sensor está colocado muy cerca del techo y del punto de iluminación.

Esto puede ser bueno para evitar contacto con agua directa, pero introduce una cuestión:

\[Inferencia\] Si la luminaria o el propio techo generan un gradiente térmico apreciable, la temperatura medida por el DHT22 puede no representar exactamente la temperatura media del aire del baño.

Eso afecta directamente a la humedad absoluta calculada.

No lo considero un defecto demostrado porque no hay mediciones comparativas.

Pero sería una comprobación experimental muy útil:

> comparar DHT22 colocado en su posición actual frente a otro sensor de referencia temporalmente colocado en el centro del volumen de aire.

---

# 14\. Software: arquitectura

La máquina de estados está bastante bien planteada.

No encuentro una estructura de software innecesariamente complicada.

El uso de `enum estado` es apropiado y facilita bastante la revisión.

La documentación UML también ayuda.

### Pero existe una discrepancia

El diagrama habla conceptualmente de:

> "máximo de errores"

> "sensor congelado"

> "nuevo aumento de humedad"

pero algunos contadores implementan realmente comportamientos diferentes de los que sugieren los nombres/comentarios.

En particular:

-   `contadorFallos` no representa exclusivamente fallos consecutivos;
    
-   `contadorHumedadAlta` no representa ocho incrementos consecutivos;
    
-   `contadorIguales` puede representar estabilidad física real.

La máquina de estados es buena, pero **la semántica de los contadores debería ser más rigurosa**.

---

# 15\. El contador de fallos no es estrictamente consecutivo

Código:

```
C++

```
contadorFallos++;

...

if (contadorFallos>0)
    contadorFallos--;
```
```

Por tanto, la secuencia:

```
```
error
error
correcto
error
error
```
```

puede acabar alcanzando el límite aunque los errores no hayan sido consecutivos.

Eso no es necesariamente malo.

De hecho, puede ser deliberado:

> acumular evidencia de sensor poco fiable.

El problema es que el comentario dice:

```
C++

```
MAX_FALLOS = 4//1 minuto continuado sin lecturas válidas
```
```

Eso no es exactamente lo que implementa.

### Mi valoración

**La estrategia puede ser válida.**

Lo que cambiaría es la especificación/documentación para que describa lo que realmente hace.

---

# 16\. El sensor se consulta cada 15 segundos

Aunque:

```
C++

```
INTERVALO = 5000
```
```

parezca indicar una lectura cada 5 s, la función necesita tres llamadas:

1.  primera → devuelve `0`
    
2.  segunda → devuelve `0`
    
3.  tercera → calcula la mediana

Por tanto:

**una decisión efectiva cada 15 segundos.**

Esto está bien para un fenómeno lento como la humedad de un baño.

No veo motivo para aumentarlo a 1 s ni para usar un sensor más rápido simplemente porque sea posible.

---

# 17\. Pruebas experimentales

Aquí veo una de las principales debilidades del proyecto.

## Prueba A/B

Los resultados son:

| Prueba | Pico AH | Pico HR | Tiempo hasta fin |
| --- | --- | --- | --- |
| A, extractor OFF | 16,46 g/m³ | 93 % | 24:45 |
| B, extractor ON | 15,03 g/m³ | 86 % | 17:15 |

Después del máximo, aproximadamente:

-   A tarda 18,75 min en alcanzar el criterio;
    
-   B tarda 11,50 min.

Eso es compatible con un efecto de ventilación.

Pero no demuestra por sí solo que:

> "el extractor reduce el tiempo en 7,25 min"

porque las condiciones no fueron idénticas.

La prueba B alcanzó:

-   menor humedad absoluta máxima;
    
-   menor HR máxima;
    
-   distinta evolución térmica.

Por tanto, la perturbación inicial no fue exactamente la misma.

### Problema experimental

Solo hay:

> una prueba A + una prueba B.

No hay:

-   repetición;
    
-   aleatorización;
    
-   promedio;
    
-   desviación;
    
-   intervalo de confianza;
    
-   control de caudal de vapor;
    
-   control de temperatura exterior;
    
-   control de renovación de aire natural.

### Conclusión correcta

Los datos:

> **son compatibles con que el extractor acelere el secado**

pero no permiten cuantificar con robustez cuánto.

No considero necesario convertir el baño en un laboratorio. Para un proyecto doméstico, sería suficiente hacer, por ejemplo:

-   5–10 pruebas OFF;
    
-   5–10 pruebas ON;

bajo condiciones razonablemente similares.

Eso daría mucha más información con muy poco esfuerzo.

---

# 18\. Las pruebas reales son más interesantes que el A/B

La prueba real `Ducha_real.txt` muestra:

-   máximo aproximado: 98 % HR;
    
-   19,46 g/m³;
    
-   descenso progresivo;
    
-   final a 65 % HR y 12,33 g/m³.

Esto demuestra que el sistema responde ante un caso real.

La segunda ducha es todavía más interesante porque aparecen fallos del DHT22.

Se observan 10 eventos de lectura inválida y el sistema no se bloquea ni apaga prematuramente.

Eso proporciona evidencia real a favor de la estrategia de recuperación.

---

# 19\. Pero la prueba de sensor tiene una conclusión estadística demasiado fuerte

Los datos sí muestran:

> "hubo varios errores de lectura y el controlador continuó funcionando".

Eso está demostrado.

Lo que no demuestran es:

> "la probabilidad de fallo de una lectura es 1,3 %".

Para estimar eso correctamente necesitaríamos:

-   definir exactamente qué constituye una lectura;
    
-   definir qué constituye un ciclo;
    
-   independencia o modelo de correlación;
    
-   número suficiente de muestras;
    
-   idealmente varios sensores/unidades.

El propio README reconoce la correlación en saturación, lo cual es bueno.

La crítica aquí es que **el documento reconoce la limitación pero aun así presenta una cifra que parece más precisa de lo que realmente permiten los datos**.

---

# 20\. El script `Serial_to_csv.py` tiene problemas de calidad

Este componente está bastante por debajo del nivel del firmware.

## Problema 1 — `strip(".txt")`

```
Python

Ejecutar

```
doc_name=input().strip(".txt")
```
```

`strip()` no elimina una extensión; elimina cualquiera de esos caracteres en los extremos.

Debería utilizarse algo equivalente a una operación explícita de extensión.

---

## Problema 2 — parser excesivamente dependiente del formato

Por ejemplo:

```
Python

Ejecutar

```
line.remove(item)
```
```

supone que cada token está presente exactamente donde se espera.

Un pequeño cambio en el texto del firmware puede romper el parser.

---

## Problema 3 — errores descartados

Este bloque:

```
Python

Ejecutar

```
ifline[3] =="Error":
    line= [15*index, 0, 0, 0, 0, line[-3]]
    continue
```
```

construye información sobre el error...

y acto seguido:

```
Python

Ejecutar

```
continue
```
```

hace que esa información **no se añada a `result`**.

Por tanto, el parser no conserva realmente las líneas de error en el CSV.

Eso es importante porque el propio proyecto utiliza esos datos para analizar la fiabilidad del sensor.

---

## Problema 4 — eventos de reset descartados

```
Python

Ejecutar

```
ifline[0] =="Nuevo": continue
```
```

también elimina la información sobre el reinicio del temporizador.

Eso hace que el CSV pierda información semánticamente importante.

---

## Problema 5 — tiempo reconstruido artificialmente

El parser utiliza:

```
Python

Ejecutar

```
15*index
```
```

en lugar del timestamp real.

Eso puede ser aceptable para reconstruir una gráfica, pero no es equivalente al tiempo real del controlador.

Especialmente problemático cuando hay:

-   errores;
    
-   reset del temporizador;
    
-   variaciones del tiempo de ejecución de las lecturas.

### Prioridad

**Conveniente**, pero si el Excel se utiliza como evidencia experimental formal, pasaría a **Importante**.

---

# 21\. Documentación

La documentación es, en conjunto, mejor que la habitual en proyectos domésticos.

Especialmente:

-   README razonablemente extenso;
    
-   UML;
    
-   esquema eléctrico;
    
-   datos brutos;
    
-   Excel;
    
-   metodología;
    
-   firmware;
    
-   STL;
    
-   parser.

Eso permite reproducir gran parte del proyecto.

Pero falta una verdadera **BOM técnica**.

La BOM actual:

```
```
Arduino Nano
DHT22
Módulo de relé
Zumbador
Fuente 5V 5W
```
```

no es suficiente para reproducir una instalación eléctrica.

Debería incluir al menos:

-   fabricante;
    
-   referencia;
    
-   tensión;
    
-   corriente;
    
-   certificación;
    
-   especificación de relé;
    
-   fuente exacta;
    
-   extractor exacto;
    
-   cableado;
    
-   conectores.

---

# 22\. Tabla de problemas

| Problema | Evidencia | Tipo | Prioridad |
| --- | --- | --- | --- |
| Watchdog puede reiniciar indefinidamente | Código | Demostrado por análisis | **Crítica** |
| Timeout de 60 min reiniciable | Código | Demostrado | **Importante** |
| "6 lecturas independientes" incorrecto | Código + librería | Demostrado | **Importante** |
| Estadística del 1,3 % mal planteada | Datos + código | Demostrado | **Importante** |
| Contador de humedad no es consecutivo | Código | Demostrado | **Importante** |
| Sensor congelado puede detectar estabilidad real | Código + datos | Riesgo plausible | **Importante** |
| Relé/carga inductiva sin protección documentada | Esquema | Riesgo plausible | **Importante** |
| Fuente 5 V no identificada | BOM | No verificado | **Crítica para cerrar seguridad** |
| Protección eléctrica no documentada | Esquema | No verificado | **Crítica para cerrar seguridad** |
| UNO en esquema / Nano en BOM | Documentación | Error demostrado | **Conveniente** |
| Parser pierde errores | Código | Error demostrado | **Conveniente** |
| Parser pierde resets | Código | Error demostrado | **Conveniente** |
| Ensayo A/B n=1 | Datos | Limitación demostrada | **Importante experimentalmente** |
| Carcasa sin material/IP documentado | STL/docs | Falta de documentación | **Conveniente** |

---

# 23\. Mejoras que sí haría

## Críticas

### 1\. Cerrar la seguridad eléctrica de la instalación

**Problema:** faltan datos para demostrar que fuente, relé, envolvente, cableado y ubicación son apropiados para una instalación permanente en baño.

**Cambio:** documentar y verificar componentes y protecciones reales.

**Beneficio:** poder distinguir un prototipo funcional de una instalación eléctrica realmente apta para uso continuado.

**Coste:** principalmente documental; posiblemente sustitución de componentes.

---

### 2\. Incorporar límite absoluto de funcionamiento

**Problema:** `TIEMPO_MAX` puede reiniciarse.

**Cambio:** separar timeout absoluto y timeout de una fase.

**Beneficio:** garantía real de tiempo máximo.

**Coste:** muy bajo.

---

### 3\. Gestionar watchdog repetido

**Problema:** bloqueo → watchdog → relé ON → bloqueo puede repetirse indefinidamente.

**Cambio:** contador de resets por watchdog y condición de apagado.

**Beneficio:** mejora importante de robustez.

**Coste:** muy bajo.

---

## Importantes

### 4\. Corregir el modelo de estadística del sensor

No porque la tasa de fallo sea necesariamente alta, sino para que la conclusión experimental sea correcta.

---

### 5\. Redefinir `contadorHumedadAlta`

Si la intención es detectar una subida continua, debe representar realmente una secuencia continua.

Si la intención es acumular "evidencia" de tendencia, entonces debe cambiarse el nombre y documentarse como tal.

---

### 6\. Revisar detección de sensor congelado

No la eliminaría.

La idea es buena.

Pero buscaría una forma de distinguir:

> sensor estable

de

> sensor bloqueado.

No introduciría simplemente un filtro más sofisticado sin evidencia de que lo necesites.

---

### 7\. Verificar protección del contacto del relé

No añadiría automáticamente un snubber.

Primero:

> modelo del extractor + modelo del relé.

Después se decide si hace falta y qué tipo.

---

### 8\. Repetir el experimento A/B

Esta es probablemente la mejora experimental con mayor relación información/esfuerzo.

No hace falta realizar 100 pruebas.

Un pequeño conjunto de repeticiones bajo condiciones similares ya permitiría saber si la diferencia observada es estable.

---

# 24\. Mejoras convenientes

-   Corregir el esquema UNO/Nano.
    
-   Hacer una BOM con referencias exactas.
    
-   Mejorar `Serial_to_csv.py`.
    
-   Conservar eventos de error y reset en los datos.
    
-   Usar timestamps reales.
    
-   Documentar material de la carcasa.
    
-   Documentar el montaje del controlador.
    
-   Documentar temperatura máxima dentro del falso techo.
    
-   Separar físicamente cableado de sensor y conductores de red tanto como permita la instalación.
    
-   Documentar la resistencia/pull-up del DHT22 si no está integrada en el módulo utilizado.

---

# 25\. Cosas que NO modificaría

Esto es importante porque no creo que el proyecto necesite convertirse en algo más complejo por principio.

### No sustituiría Arduino Nano simplemente por ESP32

No aporta un beneficio claro para este proyecto.

Wi-Fi, OTA, Bluetooth, etc. no resuelven el problema fundamental.

---

### No eliminaría la humedad absoluta

Es una buena decisión.

---

### No sustituiría la mediana por un filtro sofisticado

Tres muestras y mediana son suficientes para este tipo de fenómeno.

---

### No eliminaría el control manual

Es una buena capa de independencia.

---

### No intentaría hacer que el sistema arranque automáticamente el extractor por humedad

Eso cambiaría el requisito original y eliminaría parte del control explícito del usuario.

---

### No añadiría una pantalla

No aporta prácticamente nada a la función principal.

---

### No introduciría conectividad

No hay una necesidad funcional que lo justifique.

---

### No cambiaría el DHT22 simplemente porque "no es industrial"

Para un baño doméstico, el DHT22 puede ser perfectamente razonable. El problema es conocer sus limitaciones y no exigirle una precisión que no tiene. Adafruit especifica precisamente sus límites de precisión y frecuencia de muestreo. [Adafruit](https://www.adafruit.com/product/385?utm_source=chatgpt.com)

---

# 26\. Evaluación de la calidad de ingeniería

Mi lectura global es bastante clara:

### Como proyecto doméstico/experimental

Está **bien concebido**.

Especialmente en:

-   máquina de estados;
    
-   tratamiento de errores;
    
-   documentación;
    
-   utilización de humedad absoluta;
    
-   separación entre control manual y automático;
    
-   existencia de pruebas reales;
    
-   conservación de datos brutos;
    
-   watchdog;
    
-   límite temporal;
    
-   apagado definitivo.

No es un simple:

> `if humidity > X: fanOn`

con cuatro componentes.

Hay pensamiento de ingeniería detrás.

### Donde está menos maduro

La parte que más necesita mejorar no es la lógica básica, sino la transición entre:

> **prototipo electrónico funcional**

y

> **instalación eléctrica permanente en un baño**.

Ahí faltan muchos datos objetivos.

Y, dentro del software, hay una segunda capa de problemas: varias afirmaciones del README son ligeramente más fuertes que lo que realmente demuestra el código y los datos.

---

# 27\. Síntesis final

## Fortalezas principales

1.  **Arquitectura sencilla y adecuada al problema.**
    
2.  **Uso justificado de humedad absoluta.**
    
3.  **Máquina de estados clara.**
    
4.  **Buena atención a fallos del sensor.**
    
5.  **Watchdog correctamente considerado.**
    
6.  **Control manual independiente.**
    
7.  **Tiempo máximo incorporado.**
    
8.  **Datos reales y datos brutos disponibles.**
    
9.  **La metodología reconoce algunas limitaciones estadísticas.**
    
10.  **No se ha introducido complejidad tecnológica sin necesidad.**

---

## Debilidades principales

1.  El timeout máximo puede reiniciarse y dejar de ser máximo.
    
2.  Los watchdog resets no están integrados en el mecanismo de fallo persistente.
    
3.  La afirmación de seis mediciones independientes no es correcta.
    
4.  La estimación de la tasa de error del sensor no es estadísticamente sólida.
    
5.  El contador de aumento de humedad no implementa exactamente lo que dicen sus comentarios.
    
6.  La detección de sensor congelado puede confundir estabilidad con fallo.
    
7.  El ensayo A/B es insuficiente para cuantificar el efecto del extractor.
    
8.  El diseño eléctrico carece de datos suficientes para verificar completamente la instalación.
    
9.  El relé/carga inductiva necesita documentación mucho más precisa.
    
10.  La documentación contiene inconsistencias como UNO/Nano.
    
11.  El parser de datos pierde información relevante.

---

# Errores o decisiones cuestionables

Los que considero realmente relevantes son:

-   **"60 minutos máximos" cuando el temporizador puede reiniciarse.**
    
-   **"6 lecturas independientes" cuando realmente hay 3 adquisiciones del sensor.**
    
-   **"2 minutos de humedad creciente" cuando el contador no exige consecutividad.**
    
-   **estadística de 1,3 % basada en un modelo de seis lecturas independientes.**
    
-   **presentar los ensayos A/B como evidencia más fuerte de la que permiten n=1 y condiciones diferentes.**
    
-   **documentación eléctrica insuficiente para una instalación fija de 230 V en un baño.**

No considero errores:

-   usar Arduino Nano;
    
-   utilizar DHT22;
    
-   utilizar mediana;
    
-   utilizar humedad absoluta;
    
-   mantener control manual;
    
-   usar una máquina de estados;
    
-   apagar definitivamente el Arduino al acabar.

---

# Mejoras recomendadas por prioridad

### **Críticas**

1.  Verificar/documentar la instalación eléctrica real: fuente, relé, protecciones, envolventes, ubicación respecto a volúmenes del baño y cableado.
    
2.  Añadir un límite temporal absoluto independiente de los reinicios de `tiempoInicio`.
    
3.  Gestionar watchdog resets repetidos como una condición de fallo persistente.

### **Importantes**

4.  Corregir el modelo estadístico de las lecturas.
    
5.  Redefinir correctamente el contador de tendencia de humedad.
    
6.  Revisar el criterio de sensor congelado.
    
7.  Verificar el relé frente a la carga inductiva real.
    
8.  Repetir las pruebas A/B.
    
9.  Documentar exactamente los componentes eléctricos utilizados.

### **Convenientes**

10.  Corregir UNO/Nano.
    
11.  Mejorar parser y conservación de eventos.
    
12.  Documentar carcasa, montaje y condiciones térmicas.

### **Opcionales**

13.  PCB dedicada.
    
14.  SHT31/BME280.
    
15.  Configuración inalámbrica.
    
16.  Registro histórico.

No considero que 13–16 sean necesarias para solucionar los problemas fundamentales.

---

# Aspectos que yo mantendría

La arquitectura básica:

**interruptor manual → relé → extractor**

junto con:

**DHT22 → mediana → humedad absoluta + relativa → máquina de estados → apagado definitivo**

me parece una arquitectura razonable para el objetivo.

No veo una razón técnica suficiente para sustituirla por una arquitectura mucho más compleja.

---

# Preguntas pendientes que sí pueden cambiar la evaluación

Estas son las que considero realmente importantes:

1.  **¿Cuál es el modelo exacto del extractor?** Potencia, corriente y, si aparece en la documentación, tipo de motor.
    
2.  **¿Cuál es el modelo exacto del módulo de relé?** Especialmente especificación de contactos para cargas inductivas AC.
    
3.  **¿Cuál es la referencia exacta de la fuente de 5 V / 5 W?**
    
4.  **¿El montaje de Arduino y relé está dentro de una caja/envolvente? ¿Qué IP tiene?**
    
5.  **¿Cómo están realizadas físicamente las conexiones de 230 V: bornes, WAGO, PCB, soldadura, etc.?**
    
6.  **¿Dónde está exactamente el controlador respecto a la ducha y qué altura tiene el falso techo?**
    
7.  **¿El interruptor S1 realmente corta también la alimentación de la fuente de 5 V, como parece indicar el esquema?**
    
8.  **¿Qué versión de la librería `DHT.h` utilizaste al obtener los datos?** La conclusión sobre las tres adquisiciones se mantiene para la librería Adafruit actual, pero esto permitiría cerrar la trazabilidad.
    
9.  **¿Los datos de `Ducha_real_II.txt` proceden exactamente del firmware que está actualmente en el repositorio?**

Las cuatro primeras son especialmente importantes para poder cerrar la evaluación eléctrica.

---

## Conclusión

Mi conclusión provisional es que **el núcleo de ingeniería del proyecto es bastante más sólido de lo que aparenta un montaje doméstico**, sobre todo en la arquitectura de software y en la consideración de fallos. No veo motivos para complicarlo artificialmente.

Pero también hay una diferencia importante entre que el sistema **funcione** y que su diseño esté completamente cerrado desde el punto de vista de ingeniería.

Actualmente veo tres áreas que merecen atención real:

1.  **Seguridad y trazabilidad de la parte eléctrica de 230 V.**
    
2.  **Robustez ante fallos repetitivos del firmware/sensor.**
    
3.  **Rigor de la metodología experimental y de la interpretación estadística.**

Y hay un punto que considero especialmente claro: **el firmware y la documentación no coinciden completamente en la semántica de varios mecanismos de protección**. No es un problema estético; afecta a lo que realmente se puede afirmar sobre la robustez del sistema.

Si me proporcionas los **modelos exactos de fuente, relé y extractor**, y cómo está físicamente montada la parte de 230 V, puedo cerrar la parte eléctrica/normativa con bastante más precisión. En particular, ahí sí podremos determinar si lo que ahora es un **riesgo no verificado** se convierte en una conformidad demostrable o en un problema concreto.

Para la parte normativa española, la referencia que he utilizado es el texto consolidado del REBT publicado por el BOE, incluida la ITC-BT-27 y la ITC-BT-51. [BOE+2BOE+2](https://www.boe.es/buscar/act.php?id=BOE-A-2002-18099)

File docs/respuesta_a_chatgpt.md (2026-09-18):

Pedí a ChatGPT una crítica exhaustiva al proyecto, con el siguiente prompt:

# Pregunta

Quiero que realices una **evaluación técnica completa, crítica y objetiva de este proyecto**. No quiero una valoración superficial ni que simplemente destaques lo positivo. Quiero que intentes detectar problemas, puntos débiles, errores de diseño, decisiones mejorables y oportunidades de mejora, pero sin proponer cambios por el mero hecho de cambiar algo.

### 1\. Comprensión del proyecto

Antes de evaluarlo, reconstruye mentalmente el proyecto a partir de toda la información que te proporcione.

Identifica:

-   Objetivo principal.
-   Objetivos secundarios.
-   Requisitos y restricciones.
-   Arquitectura general.
-   Principio de funcionamiento.
-   Componentes y materiales.
-   Diseño mecánico.
-   Diseño eléctrico/electrónico.
-   Software, si lo hay.
-   Proceso de fabricación y montaje.
-   Uso previsto y condiciones de funcionamiento.

Si existe información insuficiente para entender correctamente alguna parte importante, indícalo explícitamente en lugar de asumirla.

### 2\. Evaluación técnica

Analiza por separado:

**Diseño funcional**

-   Si cumple realmente el objetivo planteado.
-   Robustez del funcionamiento.
-   Posibles modos de fallo.
-   Comportamiento en condiciones normales y anómalas.
-   Dependencias o puntos únicos de fallo.

**Diseño eléctrico/electrónico**

-   Dimensionamiento.
-   Tensiones, corrientes y potencias.
-   Protecciones.
-   Calentamiento y disipación.
-   Caídas de tensión.
-   Compatibilidad entre componentes.
-   Seguridad eléctrica.
-   Fiabilidad de conexiones y cableado.

**Diseño mecánico**

-   Resistencia.
-   Rigidez.
-   Uniones.
-   Tolerancias.
-   Concentraciones de tensión.
-   Vibraciones, golpes o cargas relevantes.
-   Protección frente al entorno.
-   Facilidad de montaje y desmontaje.

**Materiales y fabricación**

-   Adecuación de los materiales.
-   Proceso de fabricación.
-   Tolerancias razonables.
-   Limitaciones del proceso utilizado.
-   Repetibilidad.
-   Facilidad de fabricación.
-   Posibles problemas de envejecimiento o degradación.

**Software**, si procede:

-   Arquitectura.
-   Lógica de funcionamiento.
-   Estados y transiciones.
-   Gestión de errores.
-   Temporización.
-   Uso de memoria y recursos.
-   Bloqueos o comportamientos inesperados.
-   Mantenibilidad.

### 3\. Seguridad y fiabilidad

Busca específicamente situaciones en las que el proyecto pueda:

-   Fallar.
-   Dañarse.
-   Provocar daños a otros elementos.
-   Crear un riesgo para las personas.
-   Degradarse con el tiempo.
-   Comportarse de forma distinta a la esperada.

Distingue entre:

-   Problemas demostrados.
-   Riesgos técnicamente plausibles.
-   Posibilidades meramente especulativas.

No presentes una posibilidad hipotética como si fuera un problema real.

### 4\. Cumplimiento técnico y normativo

Cuando sea relevante, analiza las normas, reglamentos o buenas prácticas aplicables.

Si haces referencia a una norma, reglamento o requisito legal:

-   Indica cuál es.
-   Explica qué parte es relevante.
-   No inventes requisitos.
-   Distingue entre obligación normativa y recomendación de diseño.

Si no puedes verificar una cuestión normativa, dilo explícitamente.

### 5\. Análisis de las decisiones de diseño

Para cada decisión importante, intenta determinar:

1.  Qué problema resuelve.
2.  Qué ventajas proporciona.
3.  Qué inconvenientes introduce.
4.  Qué alternativas razonables existen.
5.  En qué condiciones sería preferible cada alternativa.

No presupongas que una alternativa es mejor simplemente porque sea más sofisticada, cara, moderna o técnicamente compleja.

### 6\. Mejoras

Propón mejoras únicamente cuando exista una razón técnica concreta.

Para cada mejora indica:

-   Problema que resuelve.
-   Cambio propuesto.
-   Beneficio esperado.
-   Coste o complejidad adicional.
-   Posibles inconvenientes.
-   Prioridad.

Clasifica las mejoras como:

-   **Crítica:** debería corregirse antes de utilizar el proyecto.
-   **Importante:** mejora significativamente la seguridad, fiabilidad o funcionamiento.
-   **Conveniente:** aporta una mejora razonable, pero no es necesaria.
-   **Opcional:** mejora principalmente aspectos secundarios, estética, comodidad o experimentación.

No propongas cambios si el diseño actual ya es adecuado para su objetivo.

### 7\. Evaluación experimental

Si proporciono mediciones, pruebas o resultados experimentales:

-   Comprueba si las conclusiones están justificadas por los datos.
-   Busca variables no controladas.
-   Analiza errores de medida.
-   Diferencia correlación de causalidad.
-   Comprueba si el número de pruebas es suficiente para la conclusión que se pretende obtener.
-   Propón experimentos adicionales solamente cuando puedan aportar información relevante.

Si hay cálculos, compruébalos.

Si hay datos suficientes, realiza tú mismo los cálculos necesarios para comprobarlos.

### 8\. Iteraciones del diseño

Si proporciono versiones anteriores del proyecto, compara las iteraciones.

Determina:

-   Qué problemas solucionó cada versión.
-   Qué características se conservaron correctamente.
-   Qué compromisos aparecieron.
-   Si alguna modificación empeoró otro aspecto.
-   Si existe alguna mejora que todavía tenga una justificación técnica clara.

No supongas que una versión posterior es necesariamente mejor.

### 9\. Calidad de ingeniería

Evalúa también el proyecto como trabajo de ingeniería:

-   Claridad de requisitos.
-   Trazabilidad entre requisitos y soluciones.
-   Justificación de decisiones.
-   Coherencia entre diseño teórico y construcción real.
-   Documentación.
-   Reproducibilidad.
-   Mantenibilidad.
-   Facilidad de reparación.
-   Escalabilidad o reutilización, cuando sea relevante.
-   Relación entre complejidad y beneficio.

### 10\. Valoración final

Termina con una síntesis estructurada que incluya:

**Fortalezas principales**  
Qué está particularmente bien resuelto y por qué.

**Debilidades principales**  
Qué aspectos presentan problemas o riesgos y por qué.

**Errores o decisiones cuestionables**  
Solo cuando exista una justificación técnica clara.

**Mejoras recomendadas**  
Ordenadas por prioridad, sin convertir la lista en una colección de cambios cosméticos.

**Aspectos que NO modificarías**  
Indica qué decisiones consideras adecuadas y explica por qué. No busques mejoras artificiales.

**Preguntas pendientes**  
Solo las preguntas cuya respuesta pueda cambiar significativamente la evaluación.

### Criterios importantes

Quiero una evaluación **crítica, no complaciente**, pero también **proporcional al objetivo real del proyecto**.

No evalúes un proyecto doméstico como si fuera un producto industrial certificado si ese no es su propósito. Evalúa cada decisión en función de sus requisitos, entorno de uso, coste, complejidad y nivel de exigencia.

No confundas:

-   «Podría hacerse de otra manera» con «está mal diseñado».
-   «Existe una solución más sofisticada» con «la solución actual es inadecuada».
-   «No está certificado» con «es técnicamente inseguro».
-   Preferencias personales con requisitos técnicos.

Cuando critiques una decisión, explica **el mecanismo físico, matemático, eléctrico, mecánico o lógico que justifica la crítica**.

Cuando una conclusión dependa de una suposición, comienza esa línea con **\[Inferencia\]** o **\[No verificado\]**.

Si existen varias soluciones técnicamente válidas, no elijas arbitrariamente una: explica el compromiso entre ellas.

No intentes agradarme ni defender mis decisiones. Tampoco las critiques por defecto. Tu objetivo es determinar, con la información disponible, **qué está bien, qué está mal, qué es mejorable y qué no merece la pena tocar**.

Quiero que señales tanto los problemas que yo pueda no haber detectado como las decisiones que están bien justificadas aunque inicialmente puedan parecer poco convencionales.

Finalmente, si detectas que falta información importante, **pregúntamela antes de emitir una conclusión definitiva sobre ese aspecto**.

A continuación te adjunto toda la documentación del proyecto. Todo el contexto necesario está en el documento llamado README  
Extractor-de-humedad-(GitHub).zip

# Respuesta

Esta es, punto a punto, mi respuesta a la crítica

## 1\. Reconstrucción del proyecto

Desde luego la descripción propuesta es más precisa, pero algo compleja para mi gusto. En cuanto a la reconstrucción, sin comentarios.

## 2\. Arquitectura y funcionamiento

Sin comentarios

## 3\. Lo que está particularmente bien resuelto

Sin comentarios

## 4\. Problemas y puntos débiles importantes

Ahora empieza la parte divertida

### 4.1. \[Crítico\] El watchdog puede provocar reinicios indefinidos sin llegar al apagado seguro

Efectivamente, el watchdog no tiene límite en cuanto a reinicios. Es un problema real que requiere solución. La única medida de contingencia que hay ahora mismo al respecto es el avisador acústico específico para reinicios inesperados por watchdog.

En defensa del código actual, he de decir que no solo no se han producido este tipo de reinicios encadenados, sino que el código en si mismo no permite reinicios por watchdog de ningún tipo, por lo que es un error que no se ha dado nunca.

### 4.2. \[Crítico\] El "tiempo máximo de 60 minutos" no es realmente un máximo global

La intención del tiempo máximo es que el extractor se apague si se da el caso de que no esté ventilando correctamente, y que por lo tanto la humedad no desminuya de forma significativa. Si este fuera el caso, el reinicio del contador de tiempo solamente podría ocurrir un número limitado de veces, pues solamente admite aumentos de humedad, y solamente por encima del 80%.

En el caso de que la humedad no esté disminuyendo por un mal funcionamiento del extractor, y aumente por encima del 80%, la cantidad que puede aumentar, y, por tanto, la cantidad de veces que el controlador puede declarar un aumento y reiniciar el temporizador, está limitada por las propiedades físicas de la instalación.

A pesar de esta explicación, es posible que este sesa un defecto del firmware que requiera de una mejora, aunque es un caso que no pensé como potencialmente peligroso. En mi defensa he de decir que no se ha producido ningún caso de reinicios temporales indefinidos.

### 4.3. La afirmación de "seis lecturas independientes" no es correcta

Efectivamente, este es un fallo mío. Pensaba que efectivamente el sensor enviaba 6 lecturas independientes, pero no me di cuenta de que las lecturas se recibían en grupos de dos. Es un detalle de la documentación que debe corregirse.

En cuanto al otro apunte, las lecturas de ciclos distintos sí que son independientes entre sí, pues ocurren en ciclos de reloj distintos y con tiempo más que suficiente entre ellas. Tanto es así que las lecturas pueden ser (y son) diferentes, por eso requieren filtrado. En esta parte, ChatGPT no se equivoca.

### 4.4. La estimación estadística de la tasa de error está mal planteada

Tiene gracia que lo mencione, pues este error es tan mío como suyo. La tasa la calculó el propio ChatGPT en algún otro chat que ya está perdido. En cualquier caso, no estoy seguro de que tenga razón ahora y no antes, o viceversa. La estimación actual se basa en la interpretación errónea del punto anterior, por lo que me inclino a pensar que la probabilidad actual sea más precisa.

En cualquier caso, no se puede considerar que los errores sean sucesos aleatorios e independientes. La probabilidad de que el sensor falle condicionada a que la medida anterior también sea errónea no puede ser en ningún caso igual a la probabilidad de que falle condicionado a una medida anterior válida. Mi razonamiento es que las condiciones ambientales varían la probabilidad de fallo, por lo que en las condiciones en las que se declara un fallo, el sensor ya es más propenso a fallar. Es una característica digna de un razonamiento y un estudio estadístico más profundo.

### 4.5. El contador de "sensor congelado" puede confundir estabilidad real con fallo

"Puede" no significa que ese sea el caso. En un ambiente naturalmente cambiante como es un baño, en el que bien hay una ducha en proceso, o bien un extractor activado, los parámetros constantes no son esperables en ningún caso. Si bien es verdad que no hay ninguna justificación técnica para los 5 minutos iguales, pues es un valor ajustado a ojo, las pruebas muestran que no me equivocaba. "Podrás criticar mis métodos, pero no mis resultados".

Es más, en un ambiente en que la humedad debe cambiar, el hecho de que no cambie también es mala señal. Si durante 5 minutos con el extractor encendido la humedad no cambia, pueden estar ocurriendo, al menos, cuatro cosas:

- El extractor no está funcionando y la humedad no baja, por lo que no es deseable que permanezca activado.
- El extractor está encendido pero el sensor está congelado, por lo que tampoco es deseable que el controlador permanezca activado.
- El extractor está funconando pero el aire que entra en el baño tiene las mismas características que el que sale. Es una posiblidad un poco ridícula, pero es este caso tampoco debería estar funcionando el sistema.
- El extractor está funcionando correctamente y se está generando exactamente la misma cantidad de vapor. Es una posibilidad teórica, pero experimentalmente descartada

Solamente en un caso es peor el remedio que la enfermedad, mientras que en los otros tres funciona como se esperaría. Además, siendo honestos, es un caso ridículo. Podría mejorarse el comportamiento con otra estructura para la evaluación del sensor, pero sería demasiado código comparado con el poco beneficio que supondría.

### 4.6. `contadorHumedadAlta` tampoco cuenta realmente "2 minutos consecutivos"

Efectivamente, el comentario está sobresimplificado, llegando a ser erróneo. Conviene cambiarlo.

### 4.7. El watchdog está bien planteado, pero el relé tiene una filosofía "fail ON"

El watchdos no tiene filosofía, simplemente reinicia el programa. El estado normal del extractor durante el encendido es ON. Dado que el watchdog solamente puede reiniciar mientras el controlador está encendido, el reinicio devuelve al relé al estado en el que se encontraba, que es ON. No se da el caso de que un relé que estuviese apagado se encienda por culpa del watchdog, pues solo puede reiniciar si el relé ya estaba en ON. En este caso, la crítica no tiene sentido.

## 5\. DHT22: elección y tratamiento

Sin comentarios

## 6\. Diseño eléctrico

### 6.1. Potencia de 5 V

Efectivamente falta por documentar información sobre la fuente. Pero no toda la información es relevante:

-   aislamiento: necesario
-   certificaciones: necesario. En cualquier caso, las fuentes vendidas en la UE por marcas reconocidas son seguras.
-   protección contra cortocircuito: necesario
-   temperatura máxima: fundamentalmente ninguna fuente comercial está limitada por temperaturas para una instalación doméstica. 
-   comportamiento térmico: no se ni qué se supone que significa esto.
-   grado IP: no es relevante. Para una instalación empotrada, como es el caso, la protección IP viene dada por la propia instalación.
-   corriente real disponible: con 5W, la corriente, "real" o "inventada" es de 1A.
-   tipo de montaje: empotrada junto con el resto de la instalación. Aparece indicado en el README
-   si es una fuente apropiada para instalación permanente: obviamente debe serlo, no es necesario que lo indique. Se puede apreciar por el contexto. Sobre todo en la parte que indica que la instalación queda "escondida en el falso techo".

### 6.2. Atención al punto de alimentación del Nano

Efectivamente, hay un error en el esquema. Sin comentarios.

## 7\. Inconsistencia importante: Nano frente a UNO

Efectivamente, esto también es un error del esquema. El esquema está hecho en CADE-SIMU, que solamente dispone del Arduino UNO como símbolo, por lo que es la única forma que tenía para representar el esquema en este programa. Conviene rediseñar el esquema en un programa de electrónica (EasyEDA, fritzing o similar) o en otra aplicación de dibujo, como AutoCAD o similar.

## 8\. Relé y extractor

Dicho mal y pronto, el relé es de Aliexpress, así que a saber que características técnicas tiene. Me gustaría indicar categoría de empleo, pero solamente aparecen indicadas tensión y corriente resistiva máximas (250V, 10A). En cualquier caso, el extractor es uno convendional, de unos 15W, lo que supone, suponiendo un factor de potencia de 0,8, poco más de 80 mA.

## 9\. Protección eléctrica y normativa

Todas las indicaciones son correctas, pero cabe destacar lo siguiente. El reglamento electrotécnico establece, en su Artículo 2, apartado 2, los casos en los que será de obligado cumplimiento. El apartado 6 del mismo artículo, sin embargo, que las prescripciones generales no aplican a instalaciones de muy baja tensión, siempre que su fuente de energía sea autónoma, no se alimenten de redes destinadas a otros suministros, o que tales instalaciones sean absolutamente independientes de las redes de baja tensión con valores por encima de los fijados para tales pequeñas tensiones.

En cuanto a la ITC-BT-27, la única de las indicadas que aplica, no tiene sentido la preocupación, pues se indica claramente que la instalación se ubica en el mismo sitio que otra ya existente y, presumiblemente, ya cumpliendo el reglamento. Inclusive aunque ese no fuera el caso, el cumplimiento o no de la instalación del extractor o del punto de luz no son parte de este proyecto.

Sobre la ITC-BT-51, las instrucciones de instalación del fabricante, en este caso, son las mías, así que me aseguraré de hacerme caso a mi mismo.

## 10\. Un aspecto positivo del esquema eléctrico

Sin comentarios

## 11\. Alimentación y "bleeder resistor"

Sin comentarios

## 12\. Diseño mecánico

El material de fabricación es el PLA. Es un ambiente interior, y la pieza no soporta esfuerzos mecánicos, por lo que es un material válido. La orientación es la que el slicer defina automáticamente (y la obvia para cualquiera que tenga dos dedos de frente), el grosor de la pared viene definido por la geometría, la tolerancia en estas dimensiones es poco importante, pues el material flexa lo suficiente, la fijación es con cinta de doble cara, no hay sistema de alivio de tensión para el cable, aunque puede dejarse una coca rodeando el pin del interior si es preocupante el esfuerzo del conductor (a criterio del instalador). Evidentemente, como se puede apreciar en el diseño, no hay resistencia a la condensación, y el comportamiento al envejecimiento todavía está por ver, aunque no espero ninguna reacción extraordinaria, tratándose de PLA. 

En cuanto a las supuestas protecciones:

- Condensación: no
- Gotas: está montado del revés, no hay gotas
- Polvo: está montado del revés, tampoco hay polvo
- Manipulación accidental: estando en un techo, es poco probable que alguien alce el brazo y toque sin querer un sensor junto a un downlight a 2,55 m del suelo.

## 13\. Posible problema térmico del sensor

Una luminaria LED doméstica moderna no desprende calor significativo, pero el gradiente de temperaturas sí que puede ser significativo. Conviene medirlo.

## 14\. Software: arquitectura

Sin comentarios

## 15\. El contador de fallos no es estrictamente consecutivo

Efectivamente, el comentario es erróneo.

## 16\. El sensor se consulta cada 15 segundos

Este detalle está adecuadamente comentado en el código.

## 17\. Pruebas experimentales

El hecho de que en la prueba B la humedad y la temperatura alcancen máximos más bajos se debe a que el extractor estaba encendido. No son pruebas distintas, las diferencias en las cantidades de vapor generadas son marginales. No se alcanza el mismo máximo porque el extractor limita el aumento. Es parte del efecto que se esperaba ver. Efectivamente, el volumen de datos experimentales es limitado. Conviene mejorar.

Destaco aquí que de "poco esfuerzo" nada. Ducharme mientras el portátil está leyendo datos es sencillo, pero cronometrar cuánto tiempo sale agua, a qué temperatura, y cuánto tiempo cerrado y ventilando está el baño es un coñazo.

## 18\. Las pruebas reales son más interesantes que el A/B

Sin comentarios

## 19\. Pero la prueba de sensor tiene una conclusión estadística demasiado fuerte

Misma crítica que en el [punto 4.4](#44-la-estimación-estadística-de-la-tasa-de-error-está-mal-planteada). Nada más que decir

## 20\. El script `Serial_to_csv.py` tiene problemas de calidad

Efectivamente, el script da vergüenza. Nada más que decir.

## 21\. Documentación

Sin comentarios

## Todo lo demás

Es un resumen y poco más. Todo lo interesante queda dicho.

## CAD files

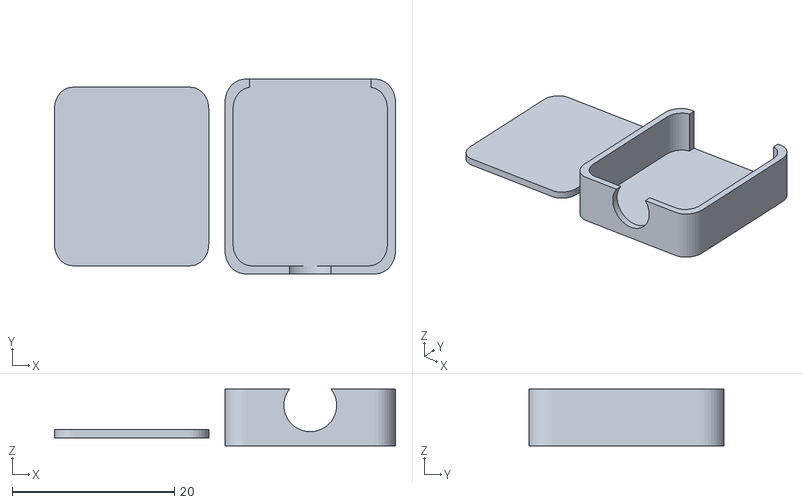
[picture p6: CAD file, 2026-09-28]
models/Caja_lector_SD.stl
42.0 x 24.0 x 7.00

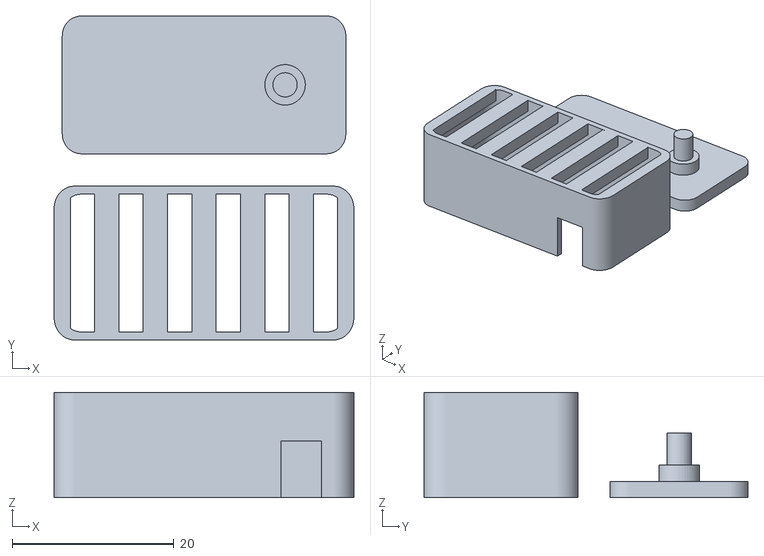
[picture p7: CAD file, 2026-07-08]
models/Caja_sensor_humedad.stl
37.0 x 40.0 x 13.0

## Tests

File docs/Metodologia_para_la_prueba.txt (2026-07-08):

Metodología para la prueba:
Condiciones iniciales:
- Humedad relativa inicial inferior al 50%
- Temperatura inicial superior a 20ºC

Durante los primeros 5 minutos: generación de vapor de agua con agua caliente con el ambiente cerrado
Durante los siguientes 10 minutos: detener la generación de vapor y añadir calor con el ambiente cerrado
Tras los primeros 15 minutos (aumentar humedad + temperatura): ventilación natural del ambiente

Pruebas A: Extractor apagado durante el transcurso de toda la prueba.
Pruebas B: Extractor encendido durante el transcurso de toda la prueba

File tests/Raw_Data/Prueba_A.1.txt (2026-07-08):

Inicio de programa
T: [0:15] --> Temperatura: 20.60ºC | Humedad relativa: 47.00% | Humedad absoluta: 8.41 g/m3 | Lecturas iguales: 0 | Fallos acumulados: 0 | Esperando...
T: [0:30] --> Temperatura: 20.90ºC | Humedad relativa: 47.00% | Humedad absoluta: 8.56 g/m3 | Lecturas iguales: 0 | Fallos acumulados: 0 | Esperando...
T: [0:45] --> Temperatura: 21.10ºC | Humedad relativa: 46.00% | Humedad absoluta: 8.47 g/m3 | Lecturas iguales: 0 | Fallos acumulados: 0 | Esperando...
T: [1:00] --> Temperatura: 21.10ºC | Humedad relativa: 46.00% | Humedad absoluta: 8.47 g/m3 | Lecturas iguales: 1 | Fallos acumulados: 0 | Esperando...
T: [1:15] --> Temperatura: 21.00ºC | Humedad relativa: 46.00% | Humedad absoluta: 8.43 g/m3 | Lecturas iguales: 0 | Fallos acumulados: 0 | Esperando...
T: [1:30] --> Temperatura: 20.90ºC | Humedad relativa: 50.00% | Humedad absoluta: 9.10 g/m3 | Lecturas iguales: 0 | Fallos acumulados: 0 | Esperando...
T: [1:45] --> Temperatura: 20.80ºC | Humedad relativa: 56.00% | Humedad absoluta: 10.14 g/m3 | Lecturas iguales: 0 | Fallos acumulados: 0 | Esperando...
T: [2:00] --> Temperatura: 20.70ºC | Humedad relativa: 63.00% | Humedad absoluta: 11.34 g/m3 | Lecturas iguales: 0 | Fallos acumulados: 0 | Esperando...
T: [2:15] --> Temperatura: 20.70ºC | Humedad relativa: 68.00% | Humedad absoluta: 12.24 g/m3 | Lecturas iguales: 0 | Fallos acumulados: 0 | Esperando...
T: [2:30] --> Temperatura: 20.60ºC | Humedad relativa: 73.00% | Humedad absoluta: 13.06 g/m3 | Lecturas iguales: 0 | Fallos acumulados: 0 | Esperando...
T: [2:45] --> Temperatura: 20.60ºC | Humedad relativa: 77.00% | Humedad absoluta: 13.78 g/m3 | Lecturas iguales: 0 | Fallos acumulados: 0 | Esperando...
T: [3:00] --> Temperatura: 20.60ºC | Humedad relativa: 79.00% | Humedad absoluta: 14.14 g/m3 | Lecturas iguales: 0 | Fallos acumulados: 0 | Esperando...
T: [3:15] --> Temperatura: 20.50ºC | Humedad relativa: 81.00% | Humedad absoluta: 14.41 g/m3 | Lecturas iguales: 0 | Fallos acumulados: 0 | Esperando...
T: [3:30] --> Temperatura: 20.40ºC | Humedad relativa: 83.00% | Humedad absoluta: 14.68 g/m3 | Lecturas iguales: 0 | Fallos acumulados: 0 | Esperando...
T: [3:45] --> Temperatura: 20.40ºC | Humedad relativa: 84.00% | Humedad absoluta: 14.86 g/m3 | Lecturas iguales: 0 | Fallos acumulados: 0 | Esperando...
T: [4:00] --> Temperatura: 20.50ºC | Humedad relativa: 86.00% | Humedad absoluta: 15.30 g/m3 | Lecturas iguales: 0 | Fallos acumulados: 0 | Esperando...
T: [4:15] --> Temperatura: 20.50ºC | Humedad relativa: 87.00% | Humedad absoluta: 15.48 g/m3 | Lecturas iguales: 0 | Fallos acumulados: 0 | Esperando...
T: [4:30] --> Temperatura: 20.40ºC | Humedad relativa: 88.00% | Humedad absoluta: 15.56 g/m3 | Lecturas iguales: 0 | Fallos acumulados: 0 | Esperando...
T: [4:45] --> Temperatura: 20.30ºC | Humedad relativa: 88.00% | Humedad absoluta: 15.47 g/m3 | Lecturas iguales: 0 | Fallos acumulados: 0 | Esperando...
T: [5:00] --> Temperatura: 20.30ºC | Humedad relativa: 89.00% | Humedad absoluta: 15.65 g/m3 | Lecturas iguales: 0 | Fallos acumulados: 0 | Esperando...
T: [5:15] --> Temperatura: 20.30ºC | Humedad relativa: 90.00% | Humedad absoluta: 15.83 g/m3 | Lecturas iguales: 0 | Fallos acumulados: 0 | Esperando...
T: [5:30] --> Temperatura: 20.30ºC | Humedad relativa: 90.00% | Humedad absoluta: 15.83 g/m3 | Lecturas iguales: 1 | Fallos acumulados: 0 | Esperando...
T: [5:45] --> Temperatura: 20.40ºC | Humedad relativa: 91.00% | Humedad absoluta: 16.10 g/m3 | Lecturas iguales: 0 | Fallos acumulados: 0 | Esperando...
T: [6:00] --> Temperatura: 20.60ºC | Humedad relativa: 92.00% | Humedad absoluta: 16.46 g/m3 | Lecturas iguales: 0 | Fallos acumulados: 0 | Esperando...
T: [6:15] --> Temperatura: 20.60ºC | Humedad relativa: 92.00% | Humedad absoluta: 16.46 g/m3 | Lecturas iguales: 1 | Fallos acumulados: 0 | Esperando...
T: [6:30] --> Temperatura: 20.50ºC | Humedad relativa: 92.00% | Humedad absoluta: 16.37 g/m3 | Lecturas iguales: 0 | Fallos acumulados: 0 | Esperando...
T: [6:45] --> Temperatura: 20.40ºC | Humedad relativa: 93.00% | Humedad absoluta: 16.45 g/m3 | Lecturas iguales: 0 | Fallos acumulados: 0 | Esperando...
T: [7:00] --> Temperatura: 20.20ºC | Humedad relativa: 93.00% | Humedad absoluta: 16.26 g/m3 | Lecturas iguales: 0 | Fallos acumulados: 0 | Esperando...
T: [7:15] --> Temperatura: 20.20ºC | Humedad relativa: 93.00% | Humedad absoluta: 16.26 g/m3 | Lecturas iguales: 1 | Fallos acumulados: 0 | Esperando...
T: [7:30] --> Temperatura: 20.20ºC | Humedad relativa: 92.00% | Humedad absoluta: 16.08 g/m3 | Lecturas iguales: 0 | Fallos acumulados: 0 | Esperando...
T: [7:45] --> Temperatura: 20.20ºC | Humedad relativa: 92.00% | Humedad absoluta: 16.08 g/m3 | Lecturas iguales: 1 | Fallos acumulados: 0 | Esperando...
T: [8:00] --> Temperatura: 20.30ºC | Humedad relativa: 92.00% | Humedad absoluta: 16.18 g/m3 | Lecturas iguales: 2 | Fallos acumulados: 0 | Esperando...
T: [8:15] --> Temperatura: 20.30ºC | Humedad relativa: 91.00% | Humedad absoluta: 16.00 g/m3 | Lecturas iguales: 0 | Fallos acumulados: 0 | Esperando...
T: [8:30] --> Temperatura: 20.40ºC | Humedad relativa: 91.00% | Humedad absoluta: 16.10 g/m3 | Lecturas iguales: 0 | Fallos acumulados: 0 | Esperando...
T: [8:45] --> Temperatura: 20.50ºC | Humedad relativa: 90.00% | Humedad absoluta: 16.01 g/m3 | Lecturas iguales: 0 | Fallos acumulados: 0 | Esperando...
T: [9:00] --> Temperatura: 20.60ºC | Humedad relativa: 89.00% | Humedad absoluta: 15.93 g/m3 | Lecturas iguales: 0 | Fallos acumulados: 0 | Esperando...
T: [9:15] --> Temperatura: 20.60ºC | Humedad relativa: 89.00% | Humedad absoluta: 15.93 g/m3 | Lecturas iguales: 1 | Fallos acumulados: 0 | Esperando...
T: [9:30] --> Temperatura: 20.70ºC | Humedad relativa: 88.00% | Humedad absoluta: 15.84 g/m3 | Lecturas iguales: 0 | Fallos acumulados: 0 | Esperando...
T: [9:45] --> Temperatura: 20.80ºC | Humedad relativa: 88.00% | Humedad absoluta: 15.93 g/m3 | Lecturas iguales: 1 | Fallos acumulados: 0 | Esperando...
T: [10:00] --> Temperatura: 20.90ºC | Humedad relativa: 87.00% | Humedad absoluta: 15.84 g/m3 | Lecturas iguales: 0 | Fallos acumulados: 0 | Esperando...
T: [10:15] --> Temperatura: 21.00ºC | Humedad relativa: 86.00% | Humedad absoluta: 15.75 g/m3 | Lecturas iguales: 0 | Fallos acumulados: 0 | Esperando...
T: [10:30] --> Temperatura: 21.00ºC | Humedad relativa: 86.00% | Humedad absoluta: 15.75 g/m3 | Lecturas iguales: 1 | Fallos acumulados: 0 | Esperando...
T: [10:45] --> Temperatura: 21.10ºC | Humedad relativa: 85.00% | Humedad absoluta: 15.66 g/m3 | Lecturas iguales: 0 | Fallos acumulados: 0 | Esperando...
T: [11:00] --> Temperatura: 21.20ºC | Humedad relativa: 84.00% | Humedad absoluta: 15.57 g/m3 | Lecturas iguales: 0 | Fallos acumulados: 0 | Esperando...
T: [11:15] --> Temperatura: 21.30ºC | Humedad relativa: 84.00% | Humedad absoluta: 15.66 g/m3 | Lecturas iguales: 1 | Fallos acumulados: 0 | Esperando...
T: [11:30] --> Temperatura: 21.30ºC | Humedad relativa: 84.00% | Humedad absoluta: 15.66 g/m3 | Lecturas iguales: 2 | Fallos acumulados: 0 | Esperando...
T: [11:45] --> Temperatura: 21.40ºC | Humedad relativa: 83.00% | Humedad absoluta: 15.56 g/m3 | Lecturas iguales: 0 | Fallos acumulados: 0 | Esperando...
T: [12:00] --> Temperatura: 21.40ºC | Humedad relativa: 83.00% | Humedad absoluta: 15.56 g/m3 | Lecturas iguales: 1 | Fallos acumulados: 0 | Esperando...
T: [12:15] --> Temperatura: 21.40ºC | Humedad relativa: 82.00% | Humedad absoluta: 15.37 g/m3 | Lecturas iguales: 0 | Fallos acumulados: 0 | Esperando...
T: [12:30] --> Temperatura: 21.40ºC | Humedad relativa: 82.00% | Humedad absoluta: 15.37 g/m3 | Lecturas iguales: 1 | Fallos acumulados: 0 | Esperando...
T: [12:45] --> Temperatura: 21.50ºC | Humedad relativa: 82.00% | Humedad absoluta: 15.46 g/m3 | Lecturas iguales: 0 | Fallos acumulados: 0 | Esperando...
T: [13:00] --> Temperatura: 21.50ºC | Humedad relativa: 81.00% | Humedad absoluta: 15.27 g/m3 | Lecturas iguales: 0 | Fallos acumulados: 0 | Esperando...
T: [13:15] --> Temperatura: 21.50ºC | Humedad relativa: 81.00% | Humedad absoluta: 15.27 g/m3 | Lecturas iguales: 1 | Fallos acumulados: 0 | Esperando...
T: [13:30] --> Temperatura: 21.60ºC | Humedad relativa: 81.00% | Humedad absoluta: 15.36 g/m3 | Lecturas iguales: 0 | Fallos acumulados: 0 | Esperando...
T: [13:45] --> Temperatura: 21.60ºC | Humedad relativa: 80.00% | Humedad absoluta: 15.17 g/m3 | Lecturas iguales: 0 | Fallos acumulados: 0 | Esperando...
T: [14:00] --> Temperatura: 21.70ºC | Humedad relativa: 80.00% | Humedad absoluta: 15.26 g/m3 | Lecturas iguales: 0 | Fallos acumulados: 0 | Esperando...
T: [14:15] --> Temperatura: 21.70ºC | Humedad relativa: 80.00% | Humedad absoluta: 15.26 g/m3 | Lecturas iguales: 1 | Fallos acumulados: 0 | Esperando...
T: [14:30] --> Temperatura: 21.80ºC | Humedad relativa: 80.00% | Humedad absoluta: 15.35 g/m3 | Lecturas iguales: 2 | Fallos acumulados: 0 | Esperando...
T: [14:45] --> Temperatura: 21.80ºC | Humedad relativa: 80.00% | Humedad absoluta: 15.35 g/m3 | Lecturas iguales: 3 | Fallos acumulados: 0 | Esperando...
T: [15:00] --> Temperatura: 21.80ºC | Humedad relativa: 80.00% | Humedad absoluta: 15.35 g/m3 | Lecturas iguales: 4 | Fallos acumulados: 0 | Esperando...
T: [15:15] --> Temperatura: 21.90ºC | Humedad relativa: 79.00% | Humedad absoluta: 15.24 g/m3 | Lecturas iguales: 0 | Fallos acumulados: 0 | Evaluando...
T: [15:30] --> Temperatura: 21.90ºC | Humedad relativa: 79.00% | Humedad absoluta: 15.24 g/m3 | Lecturas iguales: 1 | Fallos acumulados: 0 | Evaluando...
T: [15:45] --> Temperatura: 21.90ºC | Humedad relativa: 79.00% | Humedad absoluta: 15.24 g/m3 | Lecturas iguales: 2 | Fallos acumulados: 0 | Evaluando...
T: [16:00] --> Temperatura: 21.90ºC | Humedad relativa: 79.00% | Humedad absoluta: 15.24 g/m3 | Lecturas iguales: 3 | Fallos acumulados: 0 | Evaluando...
T: [16:15] --> Temperatura: 21.90ºC | Humedad relativa: 79.00% | Humedad absoluta: 15.24 g/m3 | Lecturas iguales: 4 | Fallos acumulados: 0 | Evaluando...
T: [16:30] --> Temperatura: 21.80ºC | Humedad relativa: 78.00% | Humedad absoluta: 14.96 g/m3 | Lecturas iguales: 0 | Fallos acumulados: 0 | Evaluando...
T: [16:45] --> Temperatura: 21.70ºC | Humedad relativa: 78.00% | Humedad absoluta: 14.88 g/m3 | Lecturas iguales: 1 | Fallos acumulados: 0 | Evaluando...
T: [17:00] --> Temperatura: 21.60ºC | Humedad relativa: 78.00% | Humedad absoluta: 14.79 g/m3 | Lecturas iguales: 0 | Fallos acumulados: 0 | Evaluando...
T: [17:15] --> Temperatura: 21.50ºC | Humedad relativa: 77.00% | Humedad absoluta: 14.52 g/m3 | Lecturas iguales: 0 | Fallos acumulados: 0 | Evaluando...
T: [17:30] --> Temperatura: 21.40ºC | Humedad relativa: 76.00% | Humedad absoluta: 14.25 g/m3 | Lecturas iguales: 0 | Fallos acumulados: 0 | Evaluando...
T: [17:45] --> Temperatura: 21.30ºC | Humedad relativa: 75.00% | Humedad absoluta: 13.98 g/m3 | Lecturas iguales: 0 | Fallos acumulados: 0 | Evaluando...
T: [18:00] --> Temperatura: 21.20ºC | Humedad relativa: 74.00% | Humedad absoluta: 13.71 g/m3 | Lecturas iguales: 0 | Fallos acumulados: 0 | Evaluando...
T: [18:15] --> Temperatura: 21.10ºC | Humedad relativa: 73.00% | Humedad absoluta: 13.45 g/m3 | Lecturas iguales: 0 | Fallos acumulados: 0 | Evaluando...
T: [18:30] --> Temperatura: 21.00ºC | Humedad relativa: 73.00% | Humedad absoluta: 13.37 g/m3 | Lecturas iguales: 0 | Fallos acumulados: 0 | Evaluando...
T: [18:45] --> Temperatura: 20.90ºC | Humedad relativa: 73.00% | Humedad absoluta: 13.29 g/m3 | Lecturas iguales: 0 | Fallos acumulados: 0 | Evaluando...
T: [19:00] --> Temperatura: 20.80ºC | Humedad relativa: 71.00% | Humedad absoluta: 12.85 g/m3 | Lecturas iguales: 0 | Fallos acumulados: 0 | Evaluando...
T: [19:15] --> Temperatura: 20.80ºC | Humedad relativa: 70.00% | Humedad absoluta: 12.67 g/m3 | Lecturas iguales: 0 | Fallos acumulados: 0 | Evaluando...
T: [19:30] --> Temperatura: 20.70ºC | Humedad relativa: 69.00% | Humedad absoluta: 12.42 g/m3 | Lecturas iguales: 0 | Fallos acumulados: 0 | Evaluando...
T: [19:45] --> Temperatura: 20.60ºC | Humedad relativa: 68.00% | Humedad absoluta: 12.17 g/m3 | Lecturas iguales: 0 | Fallos acumulados: 0 | Evaluando...
T: [20:00] --> Temperatura: 20.60ºC | Humedad relativa: 68.00% | Humedad absoluta: 12.17 g/m3 | Lecturas iguales: 1 | Fallos acumulados: 0 | Evaluando...
T: [20:15] --> Temperatura: 20.50ºC | Humedad relativa: 67.00% | Humedad absoluta: 11.92 g/m3 | Lecturas iguales: 0 | Fallos acumulados: 0 | Evaluando...
T: [20:30] --> Temperatura: 20.50ºC | Humedad relativa: 68.00% | Humedad absoluta: 12.10 g/m3 | Lecturas iguales: 0 | Fallos acumulados: 0 | Evaluando...
T: [20:45] --> Temperatura: 20.50ºC | Humedad relativa: 68.00% | Humedad absoluta: 12.10 g/m3 | Lecturas iguales: 1 | Fallos acumulados: 0 | Evaluando...
T: [21:00] --> Temperatura: 20.40ºC | Humedad relativa: 69.00% | Humedad absoluta: 12.20 g/m3 | Lecturas iguales: 0 | Fallos acumulados: 0 | Evaluando...
T: [21:15] --> Temperatura: 20.40ºC | Humedad relativa: 69.00% | Humedad absoluta: 12.20 g/m3 | Lecturas iguales: 1 | Fallos acumulados: 0 | Evaluando...
T: [21:30] --> Temperatura: 20.30ºC | Humedad relativa: 70.00% | Humedad absoluta: 12.31 g/m3 | Lecturas iguales: 0 | Fallos acumulados: 0 | Evaluando...
T: [21:45] --> Temperatura: 20.30ºC | Humedad relativa: 70.00% | Humedad absoluta: 12.31 g/m3 | Lecturas iguales: 1 | Fallos acumulados: 0 | Evaluando...
T: [22:00] --> Temperatura: 20.20ºC | Humedad relativa: 70.00% | Humedad absoluta: 12.24 g/m3 | Lecturas iguales: 2 | Fallos acumulados: 0 | Evaluando...
T: [22:15] --> Temperatura: 20.20ºC | Humedad relativa: 70.00% | Humedad absoluta: 12.24 g/m3 | Lecturas iguales: 3 | Fallos acumulados: 0 | Evaluando...
T: [22:30] --> Temperatura: 20.20ºC | Humedad relativa: 70.00% | Humedad absoluta: 12.24 g/m3 | Lecturas iguales: 4 | Fallos acumulados: 0 | Evaluando...
T: [22:45] --> Temperatura: 20.10ºC | Humedad relativa: 70.00% | Humedad absoluta: 12.17 g/m3 | Lecturas iguales: 0 | Fallos acumulados: 0 | Evaluando...
T: [23:00] --> Temperatura: 20.10ºC | Humedad relativa: 70.00% | Humedad absoluta: 12.17 g/m3 | Lecturas iguales: 1 | Fallos acumulados: 0 | Evaluando...
T: [23:15] --> Temperatura: 20.10ºC | Humedad relativa: 70.00% | Humedad absoluta: 12.17 g/m3 | Lecturas iguales: 2 | Fallos acumulados: 0 | Evaluando...
T: [23:30] --> Temperatura: 20.10ºC | Humedad relativa: 69.00% | Humedad absoluta: 11.99 g/m3 | Lecturas iguales: 0 | Fallos acumulados: 0 | Evaluando...
T: [23:45] --> Temperatura: 20.00ºC | Humedad relativa: 68.00% | Humedad absoluta: 11.75 g/m3 | Lecturas iguales: 0 | Fallos acumulados: 0 | Evaluando...
T: [24:00] --> Temperatura: 20.00ºC | Humedad relativa: 67.00% | Humedad absoluta: 11.58 g/m3 | Lecturas iguales: 0 | Fallos acumulados: 0 | Evaluando...
T: [24:15] --> Temperatura: 20.00ºC | Humedad relativa: 67.00% | Humedad absoluta: 11.58 g/m3 | Lecturas iguales: 1 | Fallos acumulados: 0 | Evaluando...
T: [24:30] --> Temperatura: 19.90ºC | Humedad relativa: 66.00% | Humedad absoluta: 11.34 g/m3 | Lecturas iguales: 0 | Fallos acumulados: 0 | Evaluando...
T: [24:45] --> Temperatura: 19.90ºC | Humedad relativa: 65.00% | Humedad absoluta: 11.17 g/m3 | Lecturas iguales: 0 | Fallos acumulados: 0 | Evaluando...
Humedad por debajo del mínimo. Apagando...
Fin de programa. Que tenga un buen día :)

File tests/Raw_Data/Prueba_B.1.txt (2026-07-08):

Inicio de programa
T: [0:15] --> Temperatura: 21.00ºC | Humedad relativa: 46.00% | Humedad absoluta: 8.43 g/m3 | Lecturas iguales: 0 | Fallos acumulados: 0 | Esperando...
T: [0:30] --> Temperatura: 21.20ºC | Humedad relativa: 46.00% | Humedad absoluta: 8.52 g/m3 | Lecturas iguales: 0 | Fallos acumulados: 0 | Esperando...
T: [0:45] --> Temperatura: 21.20ºC | Humedad relativa: 45.00% | Humedad absoluta: 8.34 g/m3 | Lecturas iguales: 0 | Fallos acumulados: 0 | Esperando...
T: [1:00] --> Temperatura: 21.20ºC | Humedad relativa: 45.00% | Humedad absoluta: 8.34 g/m3 | Lecturas iguales: 1 | Fallos acumulados: 0 | Esperando...
T: [1:15] --> Temperatura: 21.00ºC | Humedad relativa: 45.00% | Humedad absoluta: 8.24 g/m3 | Lecturas iguales: 0 | Fallos acumulados: 0 | Esperando...
T: [1:30] --> Temperatura: 20.90ºC | Humedad relativa: 46.00% | Humedad absoluta: 8.38 g/m3 | Lecturas iguales: 0 | Fallos acumulados: 0 | Esperando...
T: [1:45] --> Temperatura: 20.80ºC | Humedad relativa: 50.00% | Humedad absoluta: 9.05 g/m3 | Lecturas iguales: 0 | Fallos acumulados: 0 | Esperando...
T: [2:00] --> Temperatura: 20.70ºC | Humedad relativa: 55.00% | Humedad absoluta: 9.90 g/m3 | Lecturas iguales: 0 | Fallos acumulados: 0 | Esperando...
T: [2:15] --> Temperatura: 20.60ºC | Humedad relativa: 61.00% | Humedad absoluta: 10.92 g/m3 | Lecturas iguales: 0 | Fallos acumulados: 0 | Esperando...
T: [2:30] --> Temperatura: 20.60ºC | Humedad relativa: 66.00% | Humedad absoluta: 11.81 g/m3 | Lecturas iguales: 0 | Fallos acumulados: 0 | Esperando...
T: [2:45] --> Temperatura: 20.50ºC | Humedad relativa: 70.00% | Humedad absoluta: 12.45 g/m3 | Lecturas iguales: 0 | Fallos acumulados: 0 | Esperando...
T: [3:00] --> Temperatura: 20.40ºC | Humedad relativa: 73.00% | Humedad absoluta: 12.91 g/m3 | Lecturas iguales: 0 | Fallos acumulados: 0 | Esperando...
T: [3:15] --> Temperatura: 20.30ºC | Humedad relativa: 74.00% | Humedad absoluta: 13.01 g/m3 | Lecturas iguales: 0 | Fallos acumulados: 0 | Esperando...
T: [3:30] --> Temperatura: 20.30ºC | Humedad relativa: 76.00% | Humedad absoluta: 13.36 g/m3 | Lecturas iguales: 0 | Fallos acumulados: 0 | Esperando...
T: [3:45] --> Temperatura: 20.20ºC | Humedad relativa: 77.00% | Humedad absoluta: 13.46 g/m3 | Lecturas iguales: 0 | Fallos acumulados: 0 | Esperando...
T: [4:00] --> Temperatura: 20.20ºC | Humedad relativa: 78.00% | Humedad absoluta: 13.64 g/m3 | Lecturas iguales: 0 | Fallos acumulados: 0 | Esperando...
T: [4:15] --> Temperatura: 20.20ºC | Humedad relativa: 79.00% | Humedad absoluta: 13.81 g/m3 | Lecturas iguales: 0 | Fallos acumulados: 0 | Esperando...
T: [4:30] --> Temperatura: 20.10ºC | Humedad relativa: 81.00% | Humedad absoluta: 14.08 g/m3 | Lecturas iguales: 0 | Fallos acumulados: 0 | Esperando...
T: [4:45] --> Temperatura: 20.10ºC | Humedad relativa: 82.00% | Humedad absoluta: 14.25 g/m3 | Lecturas iguales: 0 | Fallos acumulados: 0 | Esperando...
T: [5:00] --> Temperatura: 20.10ºC | Humedad relativa: 83.00% | Humedad absoluta: 14.43 g/m3 | Lecturas iguales: 0 | Fallos acumulados: 0 | Esperando...
T: [5:15] --> Temperatura: 20.10ºC | Humedad relativa: 84.00% | Humedad absoluta: 14.60 g/m3 | Lecturas iguales: 0 | Fallos acumulados: 0 | Esperando...
T: [5:30] --> Temperatura: 20.20ºC | Humedad relativa: 85.00% | Humedad absoluta: 14.86 g/m3 | Lecturas iguales: 0 | Fallos acumulados: 0 | Esperando...
T: [5:45] --> Temperatura: 20.20ºC | Humedad relativa: 86.00% | Humedad absoluta: 15.03 g/m3 | Lecturas iguales: 0 | Fallos acumulados: 0 | Esperando...
T: [6:00] --> Temperatura: 20.10ºC | Humedad relativa: 85.00% | Humedad absoluta: 14.77 g/m3 | Lecturas iguales: 0 | Fallos acumulados: 0 | Esperando...
T: [6:15] --> Temperatura: 20.10ºC | Humedad relativa: 85.00% | Humedad absoluta: 14.77 g/m3 | Lecturas iguales: 1 | Fallos acumulados: 0 | Esperando...
T: [6:30] --> Temperatura: 20.20ºC | Humedad relativa: 84.00% | Humedad absoluta: 14.68 g/m3 | Lecturas iguales: 0 | Fallos acumulados: 0 | Esperando...
T: [6:45] --> Temperatura: 20.20ºC | Humedad relativa: 84.00% | Humedad absoluta: 14.68 g/m3 | Lecturas iguales: 1 | Fallos acumulados: 0 | Esperando...
T: [7:00] --> Temperatura: 20.30ºC | Humedad relativa: 83.00% | Humedad absoluta: 14.59 g/m3 | Lecturas iguales: 0 | Fallos acumulados: 0 | Esperando...
T: [7:15] --> Temperatura: 20.40ºC | Humedad relativa: 83.00% | Humedad absoluta: 14.68 g/m3 | Lecturas iguales: 0 | Fallos acumulados: 0 | Esperando...
T: [7:30] --> Temperatura: 20.40ºC | Humedad relativa: 82.00% | Humedad absoluta: 14.50 g/m3 | Lecturas iguales: 0 | Fallos acumulados: 0 | Esperando...
T: [7:45] --> Temperatura: 20.50ºC | Humedad relativa: 82.00% | Humedad absoluta: 14.59 g/m3 | Lecturas iguales: 0 | Fallos acumulados: 0 | Esperando...
T: [8:00] --> Temperatura: 20.60ºC | Humedad relativa: 81.00% | Humedad absoluta: 14.49 g/m3 | Lecturas iguales: 0 | Fallos acumulados: 0 | Esperando...
T: [8:15] --> Temperatura: 20.70ºC | Humedad relativa: 80.00% | Humedad absoluta: 14.40 g/m3 | Lecturas iguales: 0 | Fallos acumulados: 0 | Esperando...
T: [8:30] --> Temperatura: 20.80ºC | Humedad relativa: 80.00% | Humedad absoluta: 14.48 g/m3 | Lecturas iguales: 1 | Fallos acumulados: 0 | Esperando...
T: [8:45] --> Temperatura: 20.90ºC | Humedad relativa: 79.00% | Humedad absoluta: 14.39 g/m3 | Lecturas iguales: 0 | Fallos acumulados: 0 | Esperando...
T: [9:00] --> Temperatura: 21.00ºC | Humedad relativa: 79.00% | Humedad absoluta: 14.47 g/m3 | Lecturas iguales: 0 | Fallos acumulados: 0 | Esperando...
T: [9:15] --> Temperatura: 21.00ºC | Humedad relativa: 78.00% | Humedad absoluta: 14.29 g/m3 | Lecturas iguales: 0 | Fallos acumulados: 0 | Esperando...
T: [9:30] --> Temperatura: 21.00ºC | Humedad relativa: 78.00% | Humedad absoluta: 14.29 g/m3 | Lecturas iguales: 1 | Fallos acumulados: 0 | Esperando...
T: [9:45] --> Temperatura: 21.00ºC | Humedad relativa: 77.00% | Humedad absoluta: 14.10 g/m3 | Lecturas iguales: 0 | Fallos acumulados: 0 | Esperando...
T: [10:00] --> Temperatura: 21.00ºC | Humedad relativa: 77.00% | Humedad absoluta: 14.10 g/m3 | Lecturas iguales: 1 | Fallos acumulados: 0 | Esperando...
T: [10:15] --> Temperatura: 21.10ºC | Humedad relativa: 76.00% | Humedad absoluta: 14.00 g/m3 | Lecturas iguales: 0 | Fallos acumulados: 0 | Esperando...
T: [10:30] --> Temperatura: 21.10ºC | Humedad relativa: 75.00% | Humedad absoluta: 13.82 g/m3 | Lecturas iguales: 0 | Fallos acumulados: 0 | Esperando...
T: [10:45] --> Temperatura: 21.10ºC | Humedad relativa: 75.00% | Humedad absoluta: 13.82 g/m3 | Lecturas iguales: 1 | Fallos acumulados: 0 | Esperando...
T: [11:00] --> Temperatura: 21.10ºC | Humedad relativa: 75.00% | Humedad absoluta: 13.82 g/m3 | Lecturas iguales: 2 | Fallos acumulados: 0 | Esperando...
T: [11:15] --> Temperatura: 21.10ºC | Humedad relativa: 74.00% | Humedad absoluta: 13.63 g/m3 | Lecturas iguales: 0 | Fallos acumulados: 0 | Esperando...
T: [11:30] --> Temperatura: 21.10ºC | Humedad relativa: 74.00% | Humedad absoluta: 13.63 g/m3 | Lecturas iguales: 1 | Fallos acumulados: 0 | Esperando...
T: [11:45] --> Temperatura: 21.10ºC | Humedad relativa: 74.00% | Humedad absoluta: 13.63 g/m3 | Lecturas iguales: 2 | Fallos acumulados: 0 | Esperando...
T: [12:00] --> Temperatura: 21.10ºC | Humedad relativa: 73.00% | Humedad absoluta: 13.45 g/m3 | Lecturas iguales: 0 | Fallos acumulados: 0 | Esperando...
T: [12:15] --> Temperatura: 21.10ºC | Humedad relativa: 73.00% | Humedad absoluta: 13.45 g/m3 | Lecturas iguales: 1 | Fallos acumulados: 0 | Esperando...
T: [12:30] --> Temperatura: 21.20ºC | Humedad relativa: 73.00% | Humedad absoluta: 13.53 g/m3 | Lecturas iguales: 0 | Fallos acumulados: 0 | Esperando...
T: [12:45] --> Temperatura: 21.30ºC | Humedad relativa: 73.00% | Humedad absoluta: 13.61 g/m3 | Lecturas iguales: 1 | Fallos acumulados: 0 | Esperando...
T: [13:00] --> Temperatura: 21.30ºC | Humedad relativa: 73.00% | Humedad absoluta: 13.61 g/m3 | Lecturas iguales: 2 | Fallos acumulados: 0 | Esperando...
T: [13:15] --> Temperatura: 21.30ºC | Humedad relativa: 73.00% | Humedad absoluta: 13.61 g/m3 | Lecturas iguales: 3 | Fallos acumulados: 0 | Esperando...
T: [13:30] --> Temperatura: 21.40ºC | Humedad relativa: 72.00% | Humedad absoluta: 13.50 g/m3 | Lecturas iguales: 0 | Fallos acumulados: 0 | Esperando...
T: [13:45] --> Temperatura: 21.40ºC | Humedad relativa: 72.00% | Humedad absoluta: 13.50 g/m3 | Lecturas iguales: 1 | Fallos acumulados: 0 | Esperando...
T: [14:00] --> Temperatura: 21.40ºC | Humedad relativa: 72.00% | Humedad absoluta: 13.50 g/m3 | Lecturas iguales: 2 | Fallos acumulados: 0 | Esperando...
T: [14:15] --> Temperatura: 21.40ºC | Humedad relativa: 72.00% | Humedad absoluta: 13.50 g/m3 | Lecturas iguales: 3 | Fallos acumulados: 0 | Esperando...
T: [14:30] --> Temperatura: 21.50ºC | Humedad relativa: 72.00% | Humedad absoluta: 13.58 g/m3 | Lecturas iguales: 0 | Fallos acumulados: 0 | Esperando...
T: [14:45] --> Temperatura: 21.50ºC | Humedad relativa: 71.00% | Humedad absoluta: 13.39 g/m3 | Lecturas iguales: 0 | Fallos acumulados: 0 | Esperando...
T: [15:00] --> Temperatura: 21.40ºC | Humedad relativa: 71.00% | Humedad absoluta: 13.31 g/m3 | Lecturas iguales: 0 | Fallos acumulados: 0 | Esperando...
T: [15:15] --> Temperatura: 21.50ºC | Humedad relativa: 71.00% | Humedad absoluta: 13.39 g/m3 | Lecturas iguales: 0 | Fallos acumulados: 0 | Evaluando...
T: [15:30] --> Temperatura: 21.50ºC | Humedad relativa: 71.00% | Humedad absoluta: 13.39 g/m3 | Lecturas iguales: 1 | Fallos acumulados: 0 | Evaluando...
T: [15:45] --> Temperatura: 21.50ºC | Humedad relativa: 71.00% | Humedad absoluta: 13.39 g/m3 | Lecturas iguales: 2 | Fallos acumulados: 0 | Evaluando...
T: [16:00] --> Temperatura: 21.50ºC | Humedad relativa: 71.00% | Humedad absoluta: 13.39 g/m3 | Lecturas iguales: 3 | Fallos acumulados: 0 | Evaluando...
T: [16:15] --> Temperatura: 21.40ºC | Humedad relativa: 70.00% | Humedad absoluta: 13.12 g/m3 | Lecturas iguales: 0 | Fallos acumulados: 0 | Evaluando...
T: [16:30] --> Temperatura: 21.40ºC | Humedad relativa: 70.00% | Humedad absoluta: 13.12 g/m3 | Lecturas iguales: 1 | Fallos acumulados: 0 | Evaluando...
T: [16:45] --> Temperatura: 21.30ºC | Humedad relativa: 69.00% | Humedad absoluta: 12.86 g/m3 | Lecturas iguales: 0 | Fallos acumulados: 0 | Evaluando...
T: [17:00] --> Temperatura: 21.30ºC | Humedad relativa: 67.00% | Humedad absoluta: 12.49 g/m3 | Lecturas iguales: 0 | Fallos acumulados: 0 | Evaluando...
T: [17:15] --> Temperatura: 21.20ºC | Humedad relativa: 64.00% | Humedad absoluta: 11.86 g/m3 | Lecturas iguales: 0 | Fallos acumulados: 0 | Evaluando...
Humedad por debajo del mínimo. Apagando...
Fin de programa. Que tenga un buen día :)

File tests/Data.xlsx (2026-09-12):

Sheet: Pruebas
PRUEBA A |  |  |  |  |  |  | PRUEBA B
Timestamp | Temperatura | Humedad relativa | Humedad absoluta | Lecturas iguales | Fallos | Estado | Timestamp | Temperatura | Humedad relativa | Humedad absoluta | Lecturas iguales | Fallos | Estado
0:00:00 | 20.6 | 47 | 8.41 | 0 | 0 | 0 | 0:00:00 | 21 | 46 | 8.43 | 0 | 0 | 0
0:00:15 | 20.9 | 47 | 8.56 | 0 | 0 | 0 | 0:00:15 | 21.2 | 46 | 8.52 | 0 | 0 | 0
0:00:30 | 21.1 | 46 | 8.47 | 0 | 0 | 0 | 0:00:30 | 21.2 | 45 | 8.34 | 0 | 0 | 0
0:00:45 | 21.1 | 46 | 8.47 | 1 | 0 | 0 | 0:00:45 | 21.2 | 45 | 8.34 | 1 | 0 | 0
0:01:00 | 21 | 46 | 8.43 | 0 | 0 | 0 | 0:01:00 | 21 | 45 | 8.24 | 0 | 0 | 0
0:01:15 | 20.9 | 50 | 9.1 | 0 | 0 | 0 | 0:01:15 | 20.9 | 46 | 8.38 | 0 | 0 | 0
0:01:30 | 20.8 | 56 | 10.14 | 0 | 0 | 0 | 0:01:30 | 20.8 | 50 | 9.05 | 0 | 0 | 0
0:01:45 | 20.7 | 63 | 11.34 | 0 | 0 | 0 | 0:01:45 | 20.7 | 55 | 9.9 | 0 | 0 | 0
0:02:00 | 20.7 | 68 | 12.24 | 0 | 0 | 0 | 0:02:00 | 20.6 | 61 | 10.92 | 0 | 0 | 0
0:02:15 | 20.6 | 73 | 13.06 | 0 | 0 | 0 | 0:02:15 | 20.6 | 66 | 11.81 | 0 | 0 | 0
0:02:30 | 20.6 | 77 | 13.78 | 0 | 0 | 0 | 0:02:30 | 20.5 | 70 | 12.45 | 0 | 0 | 0
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

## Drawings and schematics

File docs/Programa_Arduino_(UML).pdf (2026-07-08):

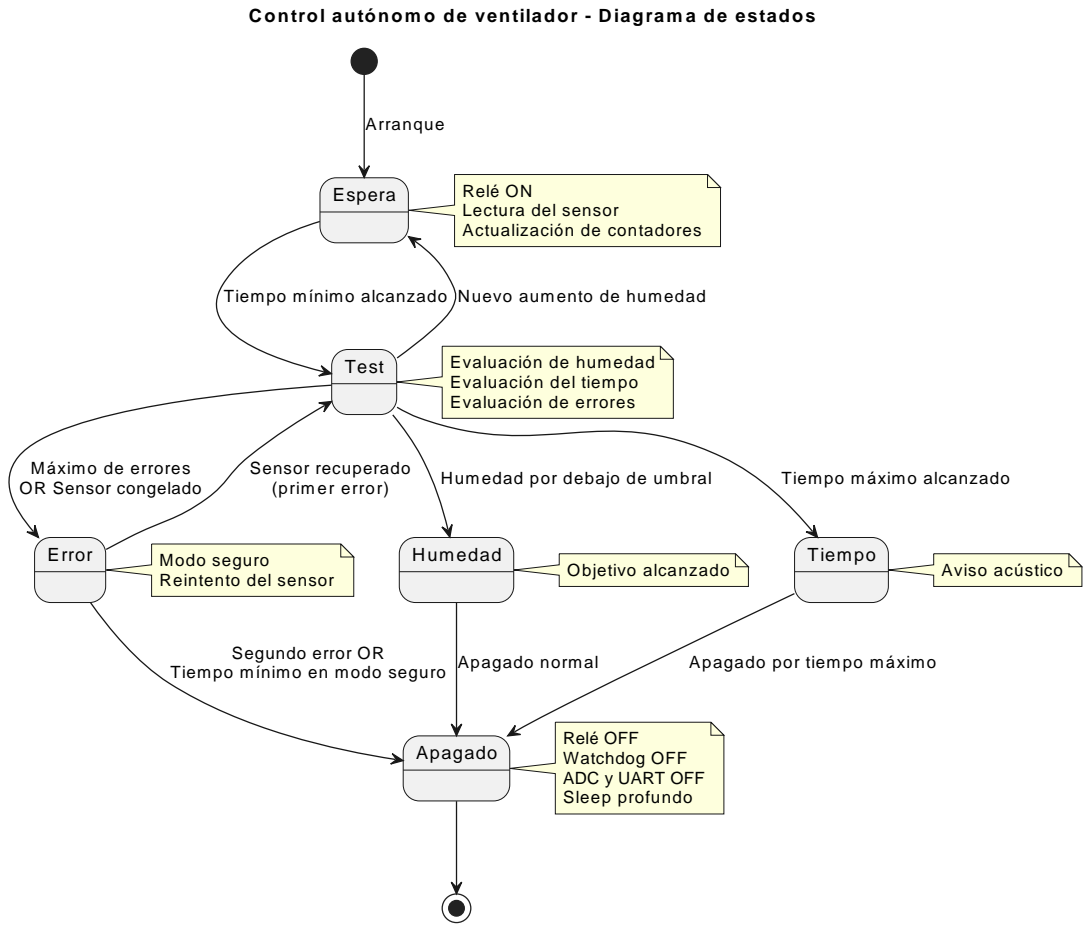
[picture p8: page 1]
Espera; Test; Error; Humedad; Tiempo; Apagado; Modo seguro; Reintento del sensor; Objetivo alcanzado; Aviso acústico; Arranque; Sensor recuperado; (prim er error); Humedad por debajo de umbral; Tiempo mínimo en modo seguro Apagado normal; Apagado por tiempo máximo

C ontrol autónom o de ventilador - D iagram a de estados

Relé ON
Lectura del sensor
Actualización de contadores

Tiempo mínimo alcanzado Nuevo aumento de humedad

Evaluación de humedad
Evaluación del tiempo
Evaluación de errores

Tiempo máximo alcanzado Máximo de errores
OR Sensor congelado

Segundo error OR

Relé OFF
Watchdog OFF
ADC y UART OFF
Sleep profundo

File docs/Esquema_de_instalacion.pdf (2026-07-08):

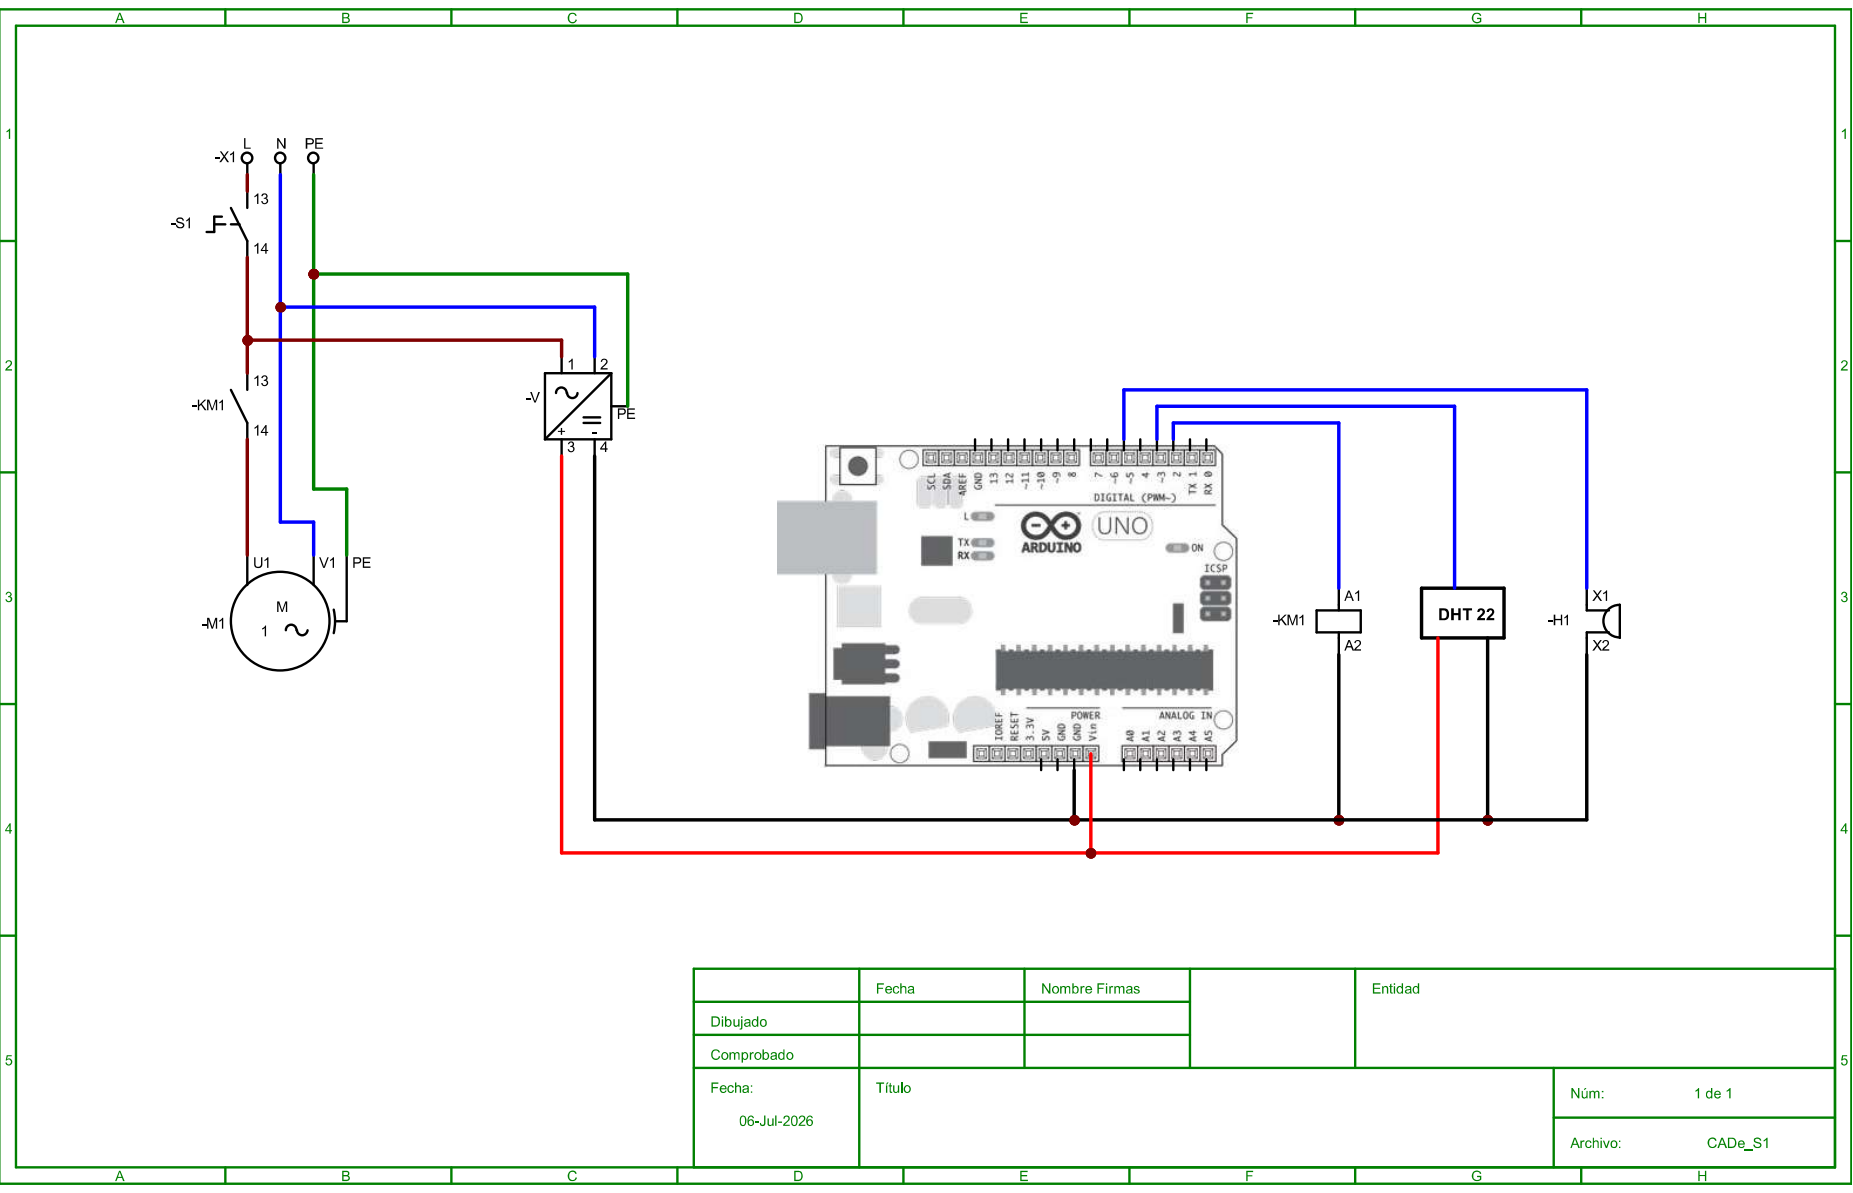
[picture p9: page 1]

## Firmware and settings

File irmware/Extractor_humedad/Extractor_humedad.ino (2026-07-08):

/*====================================================================
CONTROL AUTÓNOMO DE VENTILADOR CON DHT22

Sistema embebido para control de ventilación basado en temperatura
y humedad, con filtrado de lecturas (mediana de 3 muestras) y
máquina de estados robusta frente a fallos del sensor.

Funcionamiento:
- El ventilador arranca activado.
- Se espera un tiempo mínimo antes de evaluar apagado.
- Se decide el apagado por:
    • Humedad absoluta y relativa por debajo del umbral
    • Tiempo máximo de funcionamiento
- Se detectan errores del sensor (lecturas inválidas o congeladas).

Gestión de fallos:
- Primer error: modo seguro con intento de recuperación.
- Si el sensor se recupera, el sistema continúa.
- Error repetido: apagado definitivo por seguridad.

Finalización:
- Apaga el relé del ventilador.
- Desactiva watchdog, ADC y UART.
- Entra en sueño profundo permanente (SLEEP_MODE_PWR_DOWN).

Notas:
- La detección de reset por watchdog requiere bootloader que preserve MCUSR 
  (o programación por ISP).
- Para la versión final debe comentarse la línea: #define DEBUG
====================================================================*/
/*Definición de funciones debug (capa de depuración)
Encapsula Serial.print() con soporte de tipos y PROGMEM, eliminada completamente en compilación sin DEBUG.*/
#define DEBUG
#ifdef DEBUG
  inline void debug(const char *s) {Serial.print(s);}
  inline void debug(const __FlashStringHelper *s) {Serial.print(s);}
  inline void debug(unsigned long v) {Serial.print(v);}
  inline void debug(int v) {Serial.print(v);}
  inline void debug(float v) {Serial.print(v);}
  inline void debugln(const char *s) {Serial.println(s);}
  inline void debugln(const __FlashStringHelper *s) {Serial.println(s);}
  inline void debugln(unsigned long v) {Serial.println(v);}
  inline void debugln(int v) {Serial.println(v);}
  inline void debugln(float v) {Serial.println(v);}
#else
  inline void debug(...) {}
  inline void debugln(...) {}
#endif
//Configuración
#define AH_LIMITE 13.0 //Humedad absoluta límite (en g/m3)
#define H_LIMITE 65.0 //Humedad relativa límite (en %)
#define RESOLUCION_SENSOR 0.1 
#define MAX_FALLOS 4 //1 minuto continuado sin lecturas válidas
#define MAX_LECTURAS_IGUALES 20 //5 minutos de valores invariantes
#define H_MAXIMA 80.0 //Humedad relativa para reinicio de programa
#define UMBRAL_AUMENTO 0.5 //Pendiente de la humedad para considerar reinicio
#define CICLOS_HUMEDAD_ALTA 8 //2 minuto con humedad relativa aumentando y superior a H_MAXIMA
#define TIMEOUT_SENSOR 600 //Tiempo máximo esperable para obtener respuesta del DHT (600 ms)
const unsigned long TIEMPO_MIN = 900000; //15 minutos
const unsigned long TIEMPO_MAX = 3600000; //60 minutos
const unsigned long INTERVALO = 5000; //5 segundos · 3 lecturas

//Melodías. Importante que cada nota dure menos de 5 segundos
const int melodiaReset[] PROGMEM = {349, 330, 311, 294, 277}; // Fa, Mi, Re#, Re, Do# (5 notas. Melodía especial)
const int duracionesReset[] PROGMEM = {200, 200, 200, 200, 200}; //Todas las notas cortas
const int melodiaTiempo[] PROGMEM = {440, 440, 440}; // La, La, La
const int duracionesTiempo[] PROGMEM = {800, 200, 200}; //Primera nota larga
const int melodiaError[] PROGMEM = {440, 440, 440}; // La, La, La
const int duracionesError[] PROGMEM = {200, 800, 200}; //Segunda nota larga

//Librerías para sensor, sleep, math, lectura memoria flash y watchdog
#include <DHT.h>
#include <avr/sleep.h>
#include <math.h>
#include <avr/pgmspace.h>
#include <avr/wdt.h>

//Pines para entradas y salidas
#define RELAY 2 //Relé activo en HIGH
#define BUZZER 5 //Zumbador pasivo para aviso
#define DHTPIN 3 //Sensor de humedad y temperatura DHT22
#define DHTTYPE DHT22
DHT dht(DHTPIN, DHTTYPE);

//Variables de programa
unsigned long tiempoInicio;
unsigned long ahora;
static unsigned long ultimo = 0;
unsigned long tiempoError;
int contadorFallos = 0;
int contadorIguales = 0;
int contadorHumedadAlta = 0;
float h[3], t[3]; //Estados para la toma de medidas
int faseLectura = 0; //Memoria para la toma de medidas
float prev_humedad = 0; //Memoria para comprobación de medidas idénticas de humedad
float prev_temperatura = 0; //Memoria para comprobación de medidas idénticas de temperatura
bool errorRepetido = false; //Memoria para segunda entrada en etapaError
bool errorTiempoMaximo = false; //Memoria para tiempo máximo en etapaError
unsigned long tiempoLectura = 0; //Tiempo de inicio de la lectura del sensor

//Variables para la máquina de estados
enum estado { etapaEspera, etapaTest, etapaError, etapaHumedad, etapaTiempo, etapaApagado };
estado estadoActual = etapaEspera;

//========================= FUNCIONES ==============================
//Cálculo de la humedad absoluta
float HumedadAbsoluta(float t, float h) {
  float Pv = 6.112 * exp((17.67 * t) / (t + 243.5)); //Cálculo de la presión de vapor a una temperatura T mediante la aproximación de Magnus-Tetens
  return (h * Pv * 2.1674) / (273.15 + t); //Cálculo de la masa de agua mediante PV=nRT
}

//Cálculo de la mediana de tres lecturas consecutivas
float mediana(float a, float b, float c) {
  if (a > b) { float temporal = a; a = b; b = temporal; } //Tras este paso se garantiza a <= b
  if (b > c) { float temporal = b; b = c; c = temporal; } //Tras este paso se garantiza b <= c, pero podría romperse a <= b
  if (a > b) { float temporal = a; a = b; b = temporal; } //Se restaura el orden entre a y el nuevo b. Ahora sí: a <= b <= c
  return b;
}

//Lectura y validación del sensor
//1 para lectura correcta, 0 para lectura en proceso, -1 para error de lectura, -2 para error de rango y -3 para error de tiempo de lectura
//La validación de lecturas se da cada 15 segundos (3 lecturas)
int leerSensor(float &humedad, float &temperatura, float &agua) {
  //Primera lectura
  if (faseLectura == 0) {
    tiempoLectura = millis();
    h[0] = dht.readHumidity();
    t[0] = dht.readTemperature();
    faseLectura = 1; //Se da paso a la siguiente etapa
    //Comprobación del tiempo máximo de lectura. Detecta lecturas anormalmente largas (IMPORTANTE: NO detecta bloqueos en el DHT)
    if (millis() - tiempoLectura > TIMEOUT_SENSOR) return -3; //Si la lectura se alarga más de lo normal, se declara error y se continúa con la siguiente lectura
    //Aunque la lectura cuente como error, si el valor es válido, se sigue considerando para la toma de decisiones
    return 0;
  }
  //Segunda lectura
  if (faseLectura == 1) {
    tiempoLectura = millis();
    h[1] = dht.readHumidity();
    t[1] = dht.readTemperature();
    faseLectura = 2; //Se da paso a la siguiente etapa
    if (millis() - tiempoLectura > TIMEOUT_SENSOR) return -3;
    return 0;
  }
  //Tercera (y última) lectura
  if (faseLectura == 2) {
    tiempoLectura = millis();
    h[2] = dht.readHumidity();
    t[2] = dht.readTemperature();
    faseLectura = 0; //Se vuelve a la etapa inicial
  } 
  //Comprobación de errores de lectura (el error del DHT es NaN)
  if (isnan(h[0]) || isnan(h[1]) || isnan(h[2]) || isnan(t[0]) || isnan(t[1]) || isnan(t[2])) return -1; 
  humedad = mediana(h[0], h[1], h[2]); //Se calcula la mediana de h llamando a la función
  temperatura = mediana(t[0], t[1], t[2]); //Se calcula la mediana de t llamando a la función
  //Comprobación de valores medidos. Se declara error si el valor mediano está fuera de rango (pues los otros dos lo estarán más todavía)
  if (humedad < 0 || humedad > 100 || temperatura < -40 || temperatura > 80) return -2;
  agua = HumedadAbsoluta(temperatura, humedad); //Cálculo de la humedad absoluta llamando a la función
  if (millis() - tiempoLectura > TIMEOUT_SENSOR) return -3; //Si en la tercera lectura el valor se obtiene fuera del tiempo máximo,
  //el valor es validado como siempre, pero se declara error. Los valores siguen siendo válidos para la toma de decisiones
  return 1; //Todo ha salido bien y se devuelve un 1
}

//Imprimir tiempo por monitor serie
void tiempo(unsigned long tiempoActual) {
  unsigned long minutos = tiempoActual / 60000;
  unsigned long segundos = (tiempoActual % 60000) / 1000;
  debug(F("T: ["));
  debug(minutos); debug(F(":"));
  if(segundos < 10) debug(F("0")); //El cero antes de una única unidad
  debug(segundos); debug(F("] --> "));
}

//Imprimir datos por monitor serie
void datos(float humedad, float temperatura, float agua) {
  debug(F("Temperatura: ")); debug(temperatura);
  debug(F("ºC | Humedad relativa: ")); debug(humedad);
  debug(F("% | Humedad absoluta: ")); debug(agua); debug(F(" g/m3"));
}

//Aviso de error en el programa (para cualquier melodía)
void aviso(const int *melodia, const int *duraciones, int n) {
  debug(F("Melodía de error: 𝄞 "));
  for (int i = 0; i < n; i++) {
    int nota = pgm_read_word(&melodia[i]);
    int duracion = pgm_read_word(&duraciones[i]);
    tone(BUZZER, nota, duracion);
    delay(duracion + 50);
    wdt_reset(); //Para evitar reinicios, se despierta el watchdog con cada nota
    if (duracion < 500){debug(F("♪"));} //Es necesario añadir las llaves al if para que cuando desaparezca DEBUG_PRINT el if ejecute algo (en caso contrario aparece el error: 'else' without a previous 'if')
    else debug(F("♩"));
  }
  debugln("");
}

//Mensaje que se imprime por monitor serie (tiempo, datos, contadorIguales, contadorFallos y estado de la máquina)
void info(int variableError, int contadorFallos, int contadorIguales, unsigned long ahora, float humedad, float temperatura, float agua) {
  if (variableError == 1) {
    tiempo(ahora);
    datos(humedad, temperatura, agua);
    debug(F(" | Lecturas iguales: "));
    debug(contadorIguales);
    debug(F(" | Fallos acumulados: "));
    debug(contadorFallos);
  }
  else if (variableError == -1) {
    tiempo(ahora);
    debug(F("Error de lectura. Fallos acumulados: "));
    debug(contadorFallos);
  }
  else if (variableError == -2) {
    tiempo(ahora);
    debug(F("Error de rango. Fallos acumulados: "));
    debug(contadorFallos);
  }
  else if (variableError == -3) {
    tiempo(ahora);
    debug(F("El sensor no responde. Fallos acumulados: "));
    debug(contadorFallos);
  }
}

//Detección de reset por watchdog. Sólo funcionará si el bootloader no borra MCUSR (debe programarse por ISP)
uint8_t mcusr_mirror __attribute__((section(".noinit")));
void get_mcusr(void) __attribute__((section(".init3")));
void get_mcusr(void) {
    mcusr_mirror = MCUSR;
    MCUSR = 0;
    if (mcusr_mirror & (1 << WDRF)) {
        wdt_disable();
    }
}

//========================= MAIN ==============================
void setup() {
  dht.begin();
  #ifdef DEBUG
    Serial.begin(9600);
  #endif
  pinMode(RELAY, OUTPUT);
  pinMode(BUZZER, OUTPUT);
  digitalWrite(RELAY, HIGH);
  tiempoInicio = millis();
  debugln(F("Inicio de programa"));
  if (mcusr_mirror & (1 << WDRF)) {
    debugln(F("Reset automático por error de ejecución"));
    aviso(melodiaReset, duracionesReset, sizeof(melodiaReset)/sizeof(melodiaReset[0]));
  }
  wdt_enable(WDTO_8S); //Watchdog a 8 segundos
}

void loop() {
  wdt_reset(); //Reset del watchdog
  ahora = millis();
  if (ahora - ultimo < INTERVALO) return; //Tiempo actual por debajo del intervalo (todavía no pasaron 5 segundos desde la última medida)
  ultimo = ahora;
  //Lectura y validación de datos
  float humedad, temperatura, agua;
  int variableError = leerSensor(humedad, temperatura, agua);
  if (variableError == 0) return; //Lectura incompleta (mediana no calculada)
  if (variableError < 0) {
    contadorFallos++;
    if (contadorHumedadAlta > 0) contadorHumedadAlta--; 
    /*Si no hay lectura válida de humedad, se desecha una medida de humedad alta (evidencia débil)
    Es deseable no reiniciar el proceso en la medida de lo posible, por ese motivo las lecturas erróneas descuentan datos de humedad alta.
    Aún así, no son evidencia suficiente de que la humedad se ha reducido de manera efectiva. Ésto se hace así porque no es deseable reiniciar
    el ciclo con un sensor defectuoso o poco fiable (se penalizan lecturas erróneas para el reinicio)*/
  } 
  if (variableError == 1) {
    if (contadorFallos > 0) contadorFallos--; //Descuenta un error por cada lectura correcta (evita lecturas inconsistentes)
    if (fabs(humedad - prev_humedad) < RESOLUCION_SENSOR && fabs(temperatura - prev_temperatura) < RESOLUCION_SENSOR) contadorIguales++;
    else contadorIguales = 0;
    if (humedad > H_MAXIMA) {
        if ((humedad - prev_humedad) >= UMBRAL_AUMENTO) contadorHumedadAlta++; //Si la humedad está por encima del máximo y aumenta, incrementar contador
        //En caso contrario no hace nada (no resetea el contador si la humedad no aumenta pero sigue por encima del máximo)
    } 
    else contadorHumedadAlta = 0; //Si la lectura es inferior a 95, se resetea el contador (evidencia fuerte)
    prev_humedad = humedad;
    prev_temperatura = temperatura;
  }

  switch (estadoActual) {

    case etapaEspera:
      info(variableError, contadorFallos, contadorIguales, ahora, humedad, temperatura, agua);
      debugln(F(" | Esperando..."));
      // Transición. Pasan 15 minutos --> etapaTest
      if (ahora - tiempoInicio >= TIEMPO_MIN) estadoActual = etapaTest;
      break;

    case etapaTest:
      info(variableError, contadorFallos, contadorIguales, ahora, humedad, temperatura, agua);
      debugln(F(" | Evaluando..."));
      // Transicion. Errores máximos --> etapaError. Humedad mínima --> etapaHumedad. Tiempo máximo --> etapaTiempo
      if (ahora - tiempoInicio >= TIEMPO_MAX) estadoActual = etapaTiempo; //Tiempo máximo, comprobación prioritaria
      else if (contadorFallos >= MAX_FALLOS) {
        debugln(F("Número máximo de errores alcanzado. "));
        tiempoError = millis();
        estadoActual = etapaError; //Errores máximos, segunda comprobación
      } 
      else if (contadorIguales >= MAX_LECTURAS_IGUALES) {
        debugln(F("Sensor congelado. "));
        tiempoError = millis();
        estadoActual = etapaError; //Sensor congelado, tercera comprobación
      } 
      else if (variableError < 0) break; //En caso de lectura errónea (y NO tiempo máximo, NO errores máximos), salir de máquina de estados sin transición
      else if (contadorHumedadAlta >= CICLOS_HUMEDAD_ALTA) {
        debugln(F("Nuevo aumento de humedad detectado. Reiniciando temporizador..."));
        tiempoInicio = millis();
        estadoActual = etapaEspera; //Nuevo aumento de humedad
      }
      else if (agua <= AH_LIMITE && humedad <= H_LIMITE) estadoActual = etapaHumedad; //Última comprobación, humedad meta alcanzada
      break;

    case etapaError:
      if (errorRepetido == true || errorTiempoMaximo == true) { 
        debugln(F("Apagando..."));
        aviso(melodiaError, duracionesError, sizeof(melodiaError)/sizeof(melodiaError[0]));
        //Transición obligatoria. Siempre --> etapaApagado
        estadoActual = etapaApagado;
      } else {
        info(variableError, contadorFallos, contadorIguales, ahora, humedad, temperatura, agua);
        debugln(F("Modo seguro..."));
        //Transiciones (dentro de la misma etapa y entre etapas)
        if (ahora - tiempoError >= TIEMPO_MIN) errorTiempoMaximo = true; //Si se vuelve a superar el tiempo mínimo --> errorTiempoMaximo = true --> etapaApagado
        if (contadorFallos == 0) { //Si el sensor se recupera
          estadoActual = etapaTest; //Se vuelve a etapaTest
          errorRepetido = true; //Pero recuerda que ya estuvo en etapaError (la próxima vez apagará directamente)
        }     
      }
      break;

    case etapaHumedad:
      debugln(F("Humedad por debajo del mínimo. Apagando..."));
      //Transición obligatoria. Siempre --> etapaApagado
      estadoActual = etapaApagado;
      break;

    case etapaTiempo:
      debugln(F("Tiempo máximo alcanzado. Apagando..."));
      aviso(melodiaTiempo, duracionesTiempo, sizeof(melodiaTiempo)/sizeof(melodiaTiempo[0]));
      //Transición obligatoria. Siempre --> etapaApagado
      estadoActual = etapaApagado;
      break;

    /*Fin de programa
    La ejecución de etapaApagado bloquea definitivamente el Arduino, sin posibilidad de despertarlo mediante software. */
    case etapaApagado:
      debugln(F("Fin de programa. Que tenga un buen día :)"));
      digitalWrite(RELAY, LOW);
      #ifdef DEBUG
        Serial.flush();
      #endif
      noInterrupts(); //Desactiva todos los procesos en segundo plano (DHT, monitor serie, millis...)
      wdt_disable(); //Desactivar el watchdog para evitar reset
      ADCSRA = 0; //Apaga el Convertidor Analógico-Digital
      UCSR0B = 0; // Desactiva UART completamente (se elimina cualquier comunicación)
      PORTD &= ~(1 << PD2);  // Fuerza a LOW el relé por registro directo
      set_sleep_mode(SLEEP_MODE_PWR_DOWN); //Modo de sueño profundo
      sleep_enable();
      while (true) sleep_cpu(); //En caso de no ejecutarse esta línea, quedará en bucle infinito
      //No hay break. Etapa final 
    
    default:
      debugln(F("Ha ocurrido un error en el programa. Error en la máquina de estados"));
      while (true); //Se espera a la activación del watchdog mediante bucle infinito
  }
}

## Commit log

2026-08-29 Extractor (corrección de licencias)
2026-09-01 Extractor (actualización de licencia)
2026-09-12 Fe de errores
    - Fe de erratas
    - Incluisón de Bill Of Materials
    - Gráficos mejor distribuidos (temperatura y humedad absoluta en el mismo, humedad relativa independiente)
    - Modificación de licencias
    - Desactivación de funciones debug
    [Caja_sensor_humedad.stl, Data.xlsx]
2026-09-12 Fe de errores
2026-09-18 Crítica de IA y respuesta
2026-09-23 Add files via upload
    Vuelvo a subir el código original.
    Añado el código modificado para registro de datos
2026-09-23 Update README.md
    Modificación de link a código original
2026-09-24 Refactor and update DHT22 fan control program
2026-09-26 Adaptación para long_term_data
    [Data.xlsx]
2026-09-28 Imagen sensor y lector
2026-09-28 Enhance README with Programa_logger details and images
    Updated README to include details about Programa_logger and its functionality, added a new image, and modified the BOM section to include the micro-SD card reader.
2026-09-28 Caja lector SD
    [Caja_lector_SD.stl]
2026-09-29 Fe de errores
    Variable de la función de registro actualizada (contadorAlta)
    [Programa_logger.ino]
2026-10-02 Archivo de código UML
2026-10-04 Corrección de contadorHumedadAlta
    contadorHumedadAlta ya no puede tomar valores negativos. No afecta al funcionamiento, solamente a la toma de datos.
2026-10-04 Update README with log file details and new improvement
    Added information about log files and a idea of a second sensor for comparison.
2026-10-05 Fe de errores
    Corrección de la llamada a registrar_datos
    [Programa_logger.ino]
2026-10-10 Upload data
    [5-10 a 11-10 (2026).CSV]
